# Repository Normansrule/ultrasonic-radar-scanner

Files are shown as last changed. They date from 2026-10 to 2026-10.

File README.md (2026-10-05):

# Ultrasonic Radar Scanner

**A tiny desk console that sweeps an ultrasonic "two-eye" head on a servo and draws what it hears as a green radar-style picture on a 2.8" touch screen.**
Three modules, seven wires, four printed parts, one USB cable.






<table>
<tr>
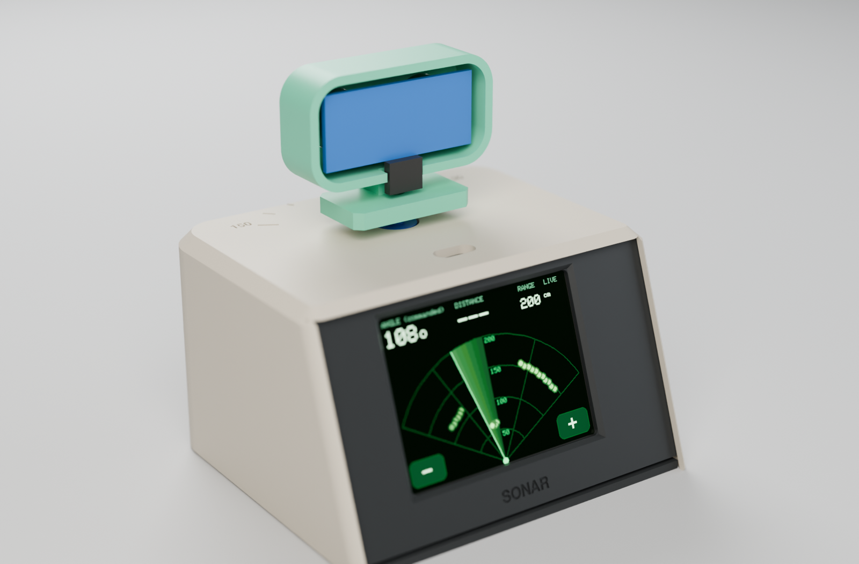
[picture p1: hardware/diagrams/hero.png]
Render: ivory console, screen tilted back, mint sensor head on a neck
<td width="62%"></td>
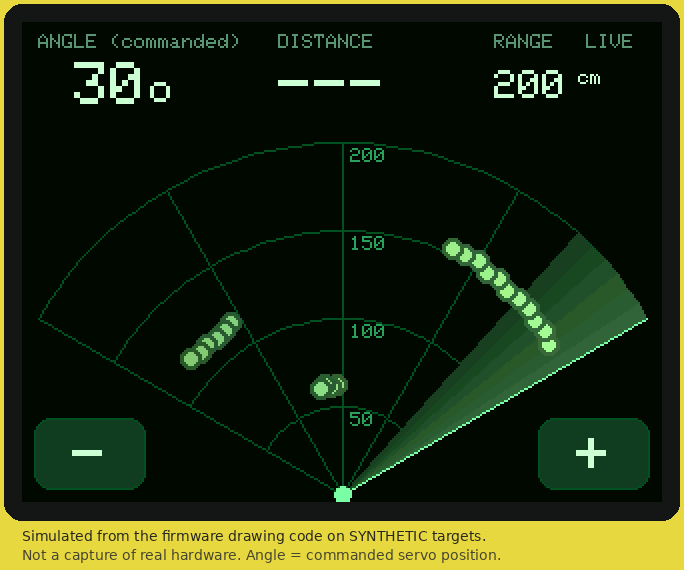
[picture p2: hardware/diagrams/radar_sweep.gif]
Simulated radar sweep
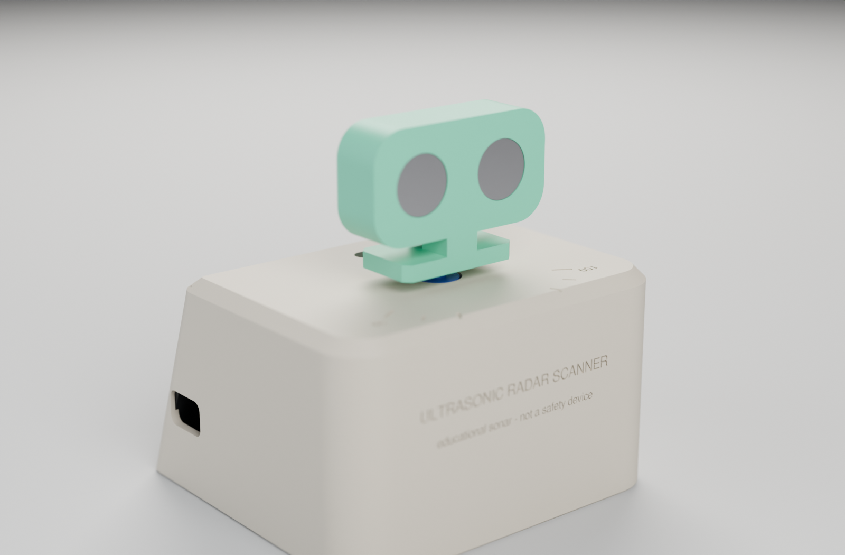
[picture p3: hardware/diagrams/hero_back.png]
Render from the scan side: the two ultrasonic eyes
<td width="38%"><br><br></td>
</tr>
<tr>
<td><sub>Render of the CadQuery model (Blender Cycles) — not a photo.</sub></td>
<td><sub>The firmware's drawing code on <b>synthetic</b> targets; the scan side.</sub></td>
</tr>
</table>

> [!IMPORTANT]
> **Educational sonar with a radar-*style* display. Not radio-frequency radar, and not a safety or obstacle-avoidance device.**
> It sweeps about 120°, and the angle shown is the *commanded* servo position. The CAD, firmware and apps pass automated checks,
> but **no V6 unit has been printed, wired or powered yet.** [`docs/VALIDATION.md`](docs/VALIDATION.md) tracks what is proven.

## The whole kit

Parts kit

| | Part | Est. US$ |
|---|---|---|
| 🖥️ | **ESP32-2432S028R "Cheap Yellow Display"** — ESP32, 2.8" 320 × 240 touch screen, RGB LED, USB | 12–20 |
| 🔊 | **RCWL-1601 or HC-SR04P** ultrasonic sensor (3.3 V version — no resistors needed) | 2–4 |
| ⚙️ | **SG90** micro servo, positional, with horn and its 2 screws | 2–3 |
| 🔌 | 3 × JST 1.25 mm 4-pin → Dupont cables, 3 male-male pins | 1–3 |
| 🖨️ | 4 printed parts, ≈ 120 g PLA, no supports | — |

Plus a USB cable and a ≥ 1 A charger or power bank. **About US$18–30 in total** — rough single-unit
estimates, not quotes. Details and what to check before buying: [`docs/BOM.md`](docs/BOM.md).

## Wire it — 7 wires

Seven wires

| Wire | From (CYD) | To |
|---|---|---|
| W1 | CN1 3.3V | sensor VCC |
| W2 | CN1 IO27 | sensor TRIG |
| W3 | P3 IO35 | sensor ECHO |
| W4 | CN1 GND | sensor GND |
| W5 | CN1 IO22 | servo signal (orange) |
| W6 | P1 VIN | servo + (red) — measure ≈ 5 V first |
| W7 | P1 GND | servo − (brown) |

Pin by pin, connector pinouts, power notes and the 5 V HC-SR04 fallback: [`docs/WIRING.md`](docs/WIRING.md).

## Build it

Build stages

1. **Print the fit coupon** — [`cad/3mf/plate_S1_fit_coupon.3mf`](cad/3mf/) — and pick peg, hole and screw sizes ([Printing](docs/PRINTING.md)).
2. **Bench test:** wire the 7 wires on the table and flash — [**Flash page**](https://normansrule.github.io/ultrasonic-radar-scanner/flash.html) in Chrome/Edge, or `arduino-cli compile --upload --profile esp32-core3 -p <port> firmware/Radar_V6`.
3. **Print** [`cad/3mf/radar_a1mini_multiplate.3mf`](cad/3mf/) — plate P1 (shell) and P2 (bezel, base, head).
4. **Assemble** in about 30 minutes ([Assembly](docs/ASSEMBLY.md)) — press fits and the servo's own two screws.
5. **Run and record** the tests in the [build packet](manufacturing/build_packet.pdf).

<table>
<tr>
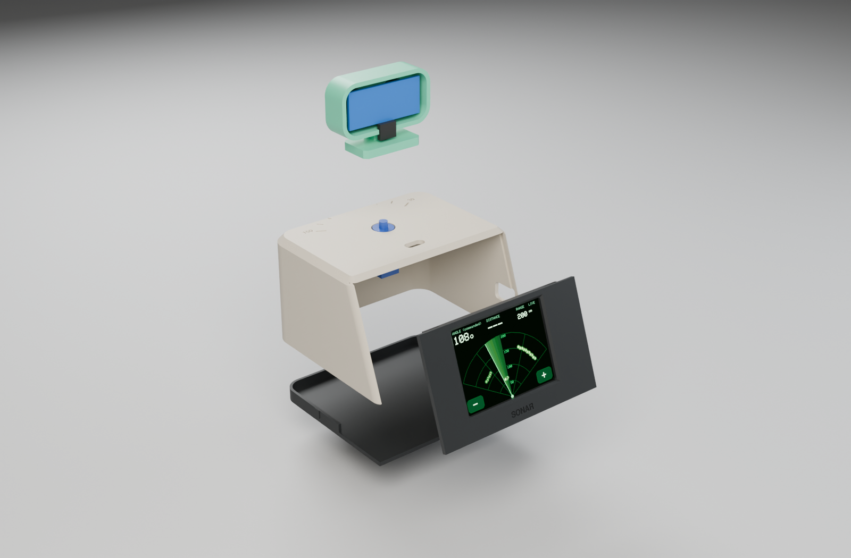
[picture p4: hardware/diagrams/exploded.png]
Exploded render
<td width="50%"></td>
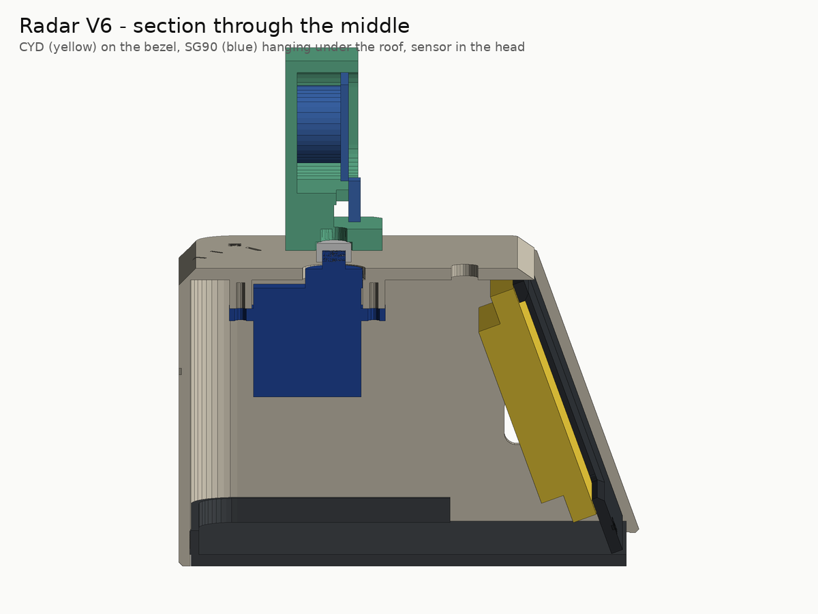
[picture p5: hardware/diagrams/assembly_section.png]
Section through the middle
<td width="50%"></td>
</tr>
<tr><td><sub>Shell · bezel (the CYD presses on) · base · head.</sub></td><td><sub>Section: CYD on the bezel, servo under the roof, sensor in the head.</sub></td></tr>
</table>

## Everything you need to make one

| | |
|---|---|
| 🧊 **3D files** | [`cad/3mf`](cad/3mf/) plates · [`cad/stl`](cad/stl/) · [`cad/step`](cad/step/) · source [`cad/build_radar.py`](cad/build_radar.py) (every dimension a named variable) |
| 🧾 **Parts list** | [`docs/BOM.md`](docs/BOM.md) · [`manufacturing/bom.csv`](manufacturing/bom.csv) |
| 🔌 **Circuit** | [`docs/WIRING.md`](docs/WIRING.md) · [`wiring_pins.csv`](manufacturing/wiring_pins.csv) · [`wire_list.csv`](manufacturing/wire_list.csv) |
| 📄 **Build packet** | [`manufacturing/build_packet.pdf`](manufacturing/build_packet.pdf) — print it, tick every step |
| ✅ **Requirements** | [`docs/REQUIREMENTS.md`](docs/REQUIREMENTS.md) — 33, each traced to a check or test |
| 💾 **Firmware** | [`firmware/Radar_V6`](firmware/Radar_V6/) — Arduino, pinned ESP32 core + libraries, compiles with 0 warnings |
| 🌐 **Apps** | [web app](https://normansrule.github.io/ultrasonic-radar-scanner/) (guide, simulator, live console, flasher) · desktop app on [Releases](https://github.com/Normansrule/ultrasonic-radar-scanner/releases/latest) |
| 📦 **Manufacturing kit** | one ZIP per [release](https://github.com/Normansrule/ultrasonic-radar-scanner/releases/latest): build packet, CSVs, 3MF/STL/STEP, diagrams, firmware |

## How it works

| | Equation | With the defaults |
|---|---|---|
| Distance | $d = v t / 2$, $v ≈ 331.3 + 0.606\,T$ | 5 823 µs at 20 °C → 100 cm |
| Servo | 50 Hz frame, 1.0–2.0 ms pulse, 16-bit duty | 90° → 1500 µs → 4915 |
| Sweep | $T = N_{moves}(t_{settle} + t_{overhead})$ | 40 × ~115 ms ≈ 4.6 s one way (estimate) |

Intuition, worked examples and plots: [`docs/EQUATIONS.md`](docs/EQUATIONS.md). Every number is re-checked by a test.

## Use it

* **On the device:** tap **−** / **+** to change the range (50–400 cm), tap the radar to pause. The LED turns red under 30 cm.
* **Live console:** plug the scanner into a computer — the same USB cable carries the readings — and open the
  [live console](https://normansrule.github.io/ultrasonic-radar-scanner/live.html) or the desktop app. Record and replay sessions ([`docs/LIVE_LINK.md`](docs/LIVE_LINK.md)).

## Publish, rebuild, contribute

* **Put it on GitHub from a fresh Ubuntu terminal:** one paste — [`docs/PUBLISH.md`](docs/PUBLISH.md).
* **Regenerate everything:** `python scripts/render_cad.py`, `render_previews.py`, `render_beauty.py` (Blender `bpy`), `sim_display.py`,
  `gen_diagrams.py`, `export_mfg.py`, `make_build_packet.py`, `gen_traceability.py`, `build_site.py`, then `python -m pytest tests`.
* **Built one?** Fill in the build packet's test sheet and send the results as a pull request to [`docs/VALIDATION.md`](docs/VALIDATION.md).

<details>
<summary><b>Repository layout</b></summary>

```
cad/build_radar.py           CadQuery source (model of record)
cad/3mf  cad/stl  cad/step    generated print files and editable CAD (never edit by hand)
firmware/Radar_V6/            Radar_V6.ino + sketch.yaml (pinned ESP32 core and libraries)
manufacturing/                bom.csv, printed_parts.csv, wiring_pins.csv, wire_list.csv, build_packet.pdf
docs/                         REQUIREMENTS, BOM, WIRING, PRINTING, ASSEMBLY, EQUATIONS, LIVE_LINK,
                              VALIDATION, SECURITY, PUBLISH, GLOSSARY
hardware/diagrams/            renders, wiring picture, parts kit, plates, GIF (all generated)
site/                         web app (GitHub Pages): landing, live console, flasher, guide
app/                          desktop app (Electron)
scripts/                      every generator, packager and exporter
tests/                        pytest, Node and browser checks
sbom/                         CycloneDX toolchain bill of materials
```
</details>

MIT licence · datasheets and credits in [`CREDITS.md`](CREDITS.md) · supply chain and electrical safety in [`docs/SECURITY.md`](docs/SECURITY.md) · terms in [`docs/GLOSSARY.md`](docs/GLOSSARY.md) · [`CHANGELOG.md`](CHANGELOG.md)

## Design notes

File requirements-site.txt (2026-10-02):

# Minimal set for building the GitHub Pages site and running the fast tests (no CAD kernel).
Markdown==3.10.2
pytest==9.1.1
# build packet PDF (scripts/make_build_packet.py)
reportlab==4.4.10
pillow==12.2.0

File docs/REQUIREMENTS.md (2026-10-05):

# Requirements and traceability

What the scanner must do, how each requirement is verified, and where the evidence lives.
Verification methods: **I**nspection, **A**nalysis, **D**emonstration, **T**est. Evidence IDs point to
[`VALIDATION.md`](VALIDATION.md): `R-…` are recorded checks a computer can run, `T-…` are physical tests.

**Status** is filled in by `python scripts/gen_traceability.py` from `VALIDATION.md`:
*Met (recorded)* = all evidence is a passing recorded check; *Open* = at least one physical test has not
been run yet. Values marked *target* are proposed goals for an educational instrument — confirm or
change them after the first bench runs.

<!-- REQS:BEGIN -->
| ID | Requirement | Method | Evidence | Status |
|---|---|---|---|---|
| RQ-F-01 | Sweep the sensor through a **commanded** 30°–150° in 3° steps and back, centring at boot. | D, A | R-EQ-1, T-FW-1, T-CAL-1 | Open |
| RQ-F-02 | Compute distance as d = v·t/2 and show 2 cm up to the selected range; show `---` for no echo or out of range. | A, T | R-EQ-1, T-FW-5 | Open |
| RQ-F-03 | Draw a radar-style display on the 320 × 240 screen: semicircular grid, sweep beam, fading detections, angle, distance and range readout. | D | R-FW-3, T-FW-1, T-FW-2 | Open |
| RQ-F-04 | Touch controls: − / + step the range through 50–400 cm; tapping the fan pauses and resumes. | D | R-FW-1, T-FW-6 | Open |
| RQ-F-05 | Provide `CENTER_ONLY` (head fitting), `REVERSE_SERVO` and `CALIBRATE_SERVO` modes. | D | R-FW-1, T-FW-3, T-CAL-1 | Open |
| RQ-F-06 | Print one `angle,distance` line per reading at 115 200 baud over the same USB cable for logging and the live console. | T | R-APP-1, T-LNK-1, T-LNK-2 | Open |
| RQ-F-07 | Run from one USB cable (charger or power bank ≥ 1 A); no battery inside. | T | R-BOM-1, T-PWR-1, T-PWR-2 | Open |
| RQ-F-08 | The on-board RGB LED turns red when something is closer than 30 cm. | D | R-FW-1, T-FW-7 | Open |
| RQ-P-01 | One-way sweep ≤ 5 s at default settings (estimate 4.6 s). | A, T | R-EQ-1, T-FW-4 | Open |
| RQ-P-02 | *Target:* distance within ±3 cm of a tape measure at 30, 100 and 150 cm on a flat target. | T | T-FW-5 | Open |
| RQ-P-03 | Servo travel calibrated without driving into its end stops. | T | T-CAL-1 | Open |
| RQ-P-04 | No resets or screen flicker over a one-hour run from a ≥ 1 A supply. | T | T-PWR-2, T-PWR-3, T-PWR-4 | Open |
| RQ-S-01 | The sensor runs from 3.3 V, so ECHO never exceeds the ESP32's 3.3 V logic; a 5 V-only sensor is used only with the documented divider. | A, I | R-EQ-1, R-SYNC-1 | Met (recorded) |
| RQ-S-02 | The servo is powered from VIN (USB 5 V), never from 3.3 V; VIN is measured before the servo is connected. | I, T | R-SYNC-1, T-PWR-1 | Open |
| RQ-S-03 | The USB serial (TX/RX) and backlight pins are never wired. | I | R-SYNC-1 | Met (recorded) |
| RQ-S-04 | The instrument is labelled "educational — not a safety device" on the case and the start-up screen. | I, D | R-CAD-1, R-FW-1, T-FW-1 | Open |
| RQ-S-05 | No part is uncomfortable to touch after 30 min running. | T | T-THM-1 | Open |
| RQ-I-01 | Every connection follows the `WIRING.md` net list, and firmware pin constants match it. | I | R-SYNC-1 | Met (recorded) |
| RQ-I-02 | ESP32-2432S028R (CYD) with ILI9341 or ST7789 panel; no flash pins used, no strapping pins on the external wires, no outputs on input-only pins. | I | R-SYNC-1, T-FW-2 | Open |
| RQ-I-03 | Seven wires, all through the CYD's JST connectors: no breadboard, no soldering to the board. | I | R-SYNC-1, R-MFG-1 | Met (recorded) |
| RQ-M-01 | Every printed part fits a Bambu Lab A1 mini (180 × 180 × 180 mm) and prints without supports. | A, T | R-CAD-3, T-PRN-2, T-PRN-3 | Open |
| RQ-M-02 | No loose fasteners: press fits plus the screws that come with the servo. | I, T | R-BOM-1, T-FIT-2, T-FIT-3 | Open |
| RQ-M-03 | The head and horn clear the shell and servo through the commanded travel plus 15° margin. | A, T | R-CAD-5, T-SWP-1 | Open |
| RQ-M-04 | Peg, sensor-hole and screw-pilot allowances are confirmed with the fit coupon before the full print. | T | T-PRN-1 | Open |
| RQ-M-05 | Modules (CYD, servo, sensor) fit without force; no model interference. | A, T | R-CAD-4, T-FIT-1, T-FIT-3, T-FIT-4 | Open |
| RQ-M-06 | All CAD outputs regenerate from one CadQuery source as valid, watertight single solids. | A | R-CAD-1, R-CAD-2 | Met (recorded) |
| RQ-M-07 | Minimum parts: 5 purchased items (+1 optional) and 4 printed parts. | I | R-BOM-1, R-MFG-1 | Met (recorded) |
| RQ-SW-01 | Firmware compiles with zero warnings on the pinned ESP32 cores 3.x and 2.x. | T | R-FW-1, R-FW-2 | Met (recorded) |
| RQ-SW-02 | No Wi-Fi or Bluetooth in the firmware; the consoles never write to the scanner. | I | R-SYNC-1, R-APP-5 | Met (recorded) |
| RQ-SW-03 | Build guide, simulator and live console work offline in the web app and the desktop app on Linux, Windows and macOS. | T | R-APP-2, R-APP-3, T-APP-1, T-APP-2 | Open |
| RQ-SW-04 | Firmware can be installed from a browser without installing a toolchain. | D | R-FLS-1, T-FLS-1 | Open |
| RQ-SW-05 | Every release carries checksums, a build-provenance attestation and a toolchain SBOM. | I | T-REL-1 | Open |
| RQ-O-01 | Everything needed to build it is in editable open formats (CadQuery, STEP, STL/3MF, Markdown, CSV) under the MIT licence. | I | R-CAD-1, R-BOM-1 | Met (recorded) |
<!-- REQS:END -->

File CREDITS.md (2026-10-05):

# Credits and sources

Every module datasheet the design relies on, and what was taken from it. "Checked" means the value
was read from the linked source while writing this repository (2026-09-30 to 2026-10-04); "unverified" means it
is a typical value that could not be confirmed from a primary source — treat it as a ## Module datasheets and product pages

| Module | Source | Used for | Status |
|---|---|---|---|
| ESP32-2432S028R "Cheap Yellow Display" | [witnessmenow/ESP32-Cheap-Yellow-Display](https://github.com/witnessmenow/ESP32-Cheap-Yellow-Display) (MIT) — `PINS.md`, schematics, community 3D model | display SPI (14/12/13/15/2, backlight 21), touch SPI (25/39/32/33/36), RGB LED (4/16/17, active low), connectors CN1 (GND/IO22/IO27/3.3V), P3 (GND/IO35/IO22/IO21), P1 (VIN/TX/RX/GND), board outline and holes | checked from the community documentation; **not** a manufacturer datasheet — clones vary, VERIFY |
| CYD pinout cross-checks | [Random Nerd Tutorials — CYD pinout](https://randomnerdtutorials.com/esp32-cheap-yellow-display-cyd-pinout-esp32-2432s028r/) · [Mischianti — ESP32-2432S028 pinout and schema](https://mischianti.org/esp32-2432s028-cheap-yellow-display-high-resolution-pinout-datasheet-schema-and-specs/) | same pins from independent write-ups; CYD2USB (ST7789) variant notes | cross-checked |
| ESP32 chip | [Espressif ESP32 series datasheet](https://www.espressif.com/sites/default/files/documentation/esp32_datasheet_en.pdf) | input-high threshold 0.75·VDD, absolute maximum VDD + 0.3 V, strapping pins (0, 2, 5, 12, 15), flash pins (6–11), input-only pins (34–39) | values as commonly quoted — confirm in the DC-characteristics table |
| RCWL-1601 ultrasonic sensor | [Adafruit 4007 — Ultrasonic Distance Sensor, 3 V or 5 V](https://www.adafruit.com/product/4007) | runs from 3–5 V, so at 3.3 V its ECHO is 3.3 V logic; HC-SR04 footprint | checked (product page) |
| HC-SR04 (footprint and fallback) | [ElecFreaks HC-SR04 datasheet (SparkFun mirror)](https://cdn.sparkfun.com/datasheets/Sensors/Proximity/HCSR04.pdf) | 10 µs trigger, ECHO pulse width ∝ distance, ≥ 60 ms cycle, 45 × 20 mm board, 5 V ECHO on the classic part | datasheet located; can diameter and pitch **unverified** across clones |
| ILI9341 controller | [Adafruit ILI9341 library](https://github.com/adafruit/Adafruit_ILI9341) | panel ID read (0xD3 → 0x93 0x41) for auto-detection | used as implemented in the library |
| XPT2046 touch controller | [PaulStoffregen/XPT2046_Touchscreen](https://github.com/PaulStoffregen/XPT2046_Touchscreen) | touch on its own SPI bus | used as implemented |
| SG90 servo | [TowerPro SG90 datasheet (DatasheetCafe copy)](https://www.datasheetcafe.com/sg90-datasheet-pdf-9-g-micro-servo/) | 22.2 × 11.8 × 31 mm, 4.8–5 V, 0.1 s/60°, 10 µs dead band | overall size checked; flange, hole pitch, shaft offset and horn dimensions **unverified** |

verified** |

## Software and references

| Item | Source |
|---|---|
| ESP Web Tools 10.4.0 (browser flasher) | [github.com/esphome/esp-web-tools](https://github.com/esphome/esp-web-tools) (Apache-2.0), loaded from unpkg.com on the Flash page |
| ReportLab 4.4 (build packet PDF) | [reportlab.com/opensource](https://www.reportlab.com/opensource/) (BSD) |
| DejaVu Sans fonts (in `manufacturing/fonts/`) | [dejavu-fonts.github.io](https://dejavu-fonts.github.io/) — Bitstream Vera licence, copy in `manufacturing/fonts/LICENSE-DejaVu.txt` |
| Arduino-ESP32 core, LEDC API | [Espressif — LEDC API](https://docs.espressif.com/projects/arduino-esp32/en/latest/api/ledc.html) and the [2.x → 3.0 migration guide](https://docs.espressif.com/projects/arduino-esp32/en/latest/migration_guides/2.x_to_3.0.html) (ledcSetup/ledcAttachPin → ledcAttach) |
| Adafruit GFX Library 1.12.6 | [github.com/adafruit/Adafruit-GFX-Library](https://github.com/adafruit/Adafruit-GFX-Library) (BSD licence) |
| Adafruit ILI9341 1.6.4 | [github.com/adafruit/Adafruit_ILI9341](https://github.com/adafruit/Adafruit_ILI9341) (MIT licence) |
| XPT2046_Touchscreen 1.4 | [github.com/PaulStoffregen/XPT2046_Touchscreen](https://github.com/PaulStoffregen/XPT2046_Touchscreen) |
| Blender 4.2 (`bpy`, renders) | [blender.org](https://www.blender.org/) (GPL; used as a tool, nothing redistributed) |
| Adafruit ST7735 and ST7789 Library 1.11.0 | [github.com/adafruit/Adafruit-ST7735-Library](https://github.com/adafruit/Adafruit-ST7735-Library) (MIT licence) |
| Adafruit BusIO 1.17.4 | [github.com/adafruit/Adafruit_BusIO](https://github.com/adafruit/Adafruit_BusIO) (MIT licence) |
| CadQuery 2.8 | [github.com/CadQuery/cadquery](https://github.com/CadQuery/cadquery) (Apache 2.0) |
| arduino-cli sketch profiles | [Arduino CLI — sketch project file](https://arduino.github.io/arduino-cli/latest/sketch-project-file/) |
| OWASP Top 10:2025 — A03 Software Supply Chain Failures | [owasp.org/Top10/2025/A03_2025-Software_Supply_Chain_Failures](https://owasp.org/Top10/2025/A03_2025-Software_Supply_Chain_Failures/) |
| Speed of sound in air, $v ≈ 331.3 + 0.606\,T$ | standard linear approximation for dry air near room temperature; e.g. [Wikipedia — Speed of sound](https://en.wikipedia.org/wiki/Speed_of_sound) |

The display simulator (`scripts/sim_display.py`) reads the 5×7 font from your locally installed
Adafruit GFX library at run time; the font is not redistributed here.

## People

Design, brief and project ownership: Aleksander Norman. Repository structure, CadQuery model,
firmware, generators and documentation drafted with AI assistance (Claude, Anthropic) and to be
reviewed and physically validated by the maintainer.

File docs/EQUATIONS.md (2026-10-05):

# Equations — how the numbers work

Every equation below follows the same pattern: **plain intuition → equation → symbols and units
→ worked example → picture.** Every number on this page is re-computed by
[`tests/test_equations.py`](../tests/test_equations.py) from one reference implementation,
[`tests/radar_math.py`](../tests/radar_math.py), whose integer maths mirrors the firmware. If a
number here and the test disagree, the test wins.

Run the checks: `python -m pytest tests/test_equations.py -v`

---

## 1. Ultrasonic distance

**Intuition.** The sensor (RCWL-1601 / HC-SR04P) clicks out a short burst of 40 kHz sound and holds its ECHO pin HIGH
until the echo comes back. Sound travels to the object *and back*, so the object is half as far
away as the total path the sound covered.

**Equation.**

$$d = \frac{v \cdot t}{2}, \qquad v \approx 331.3 + 0.606\,T$$

| Symbol | Meaning | Unit |
|---|---|---|
| $d$ | distance from the sensor face to the object | cm (firmware) |
| $v$ | speed of sound in air | m/s (÷10 000 → cm/µs) |
| $t$ | time the ECHO pin stays HIGH | µs |
| $T$ | air temperature | °C |

**Worked example.** At 20 °C, $v = 331.3 + 0.606 \times 20 = 343.42$ m/s $= 0.034342$ cm/µs.
An ECHO pulse of 5 823 µs gives $d = 5823 \times 0.034342 / 2 = 99.99 \approx 100.0$ cm.
Going the other way, 100 cm needs $t = 2 \times 100 / 0.034342 \approx 5 824$ µs.

**Temperature matters.** The same echo converted with the 20 °C constant on a 35 °C day reads
about **2.6 % short** (97.4 cm instead of 100 cm). The firmware has an `AIR_TEMP_C` setting
because there is no temperature sensor in this build.

**Timeout.** The firmware stops waiting after the round trip for 110 % of the display range, plus
1 ms for the burst to start: $2 \times 220 / 0.034342 + 1000 = 13 812$ µs. A timeout shows `---`.

Distance versus echo time at three temperatures

---

## 2. ECHO level — why V6 needs no divider

**Intuition.** The ESP32's pins are 3.3 V parts. The 3.3 V-capable sensor (RCWL-1601 / HC-SR04P) is
powered from the board's 3.3 V, so its ECHO pin can never go above 3.3 V: it connects straight to
IO35. Above the logic-HIGH threshold $0.75\,V_{DD} \approx 2.48$ V, below the absolute maximum
$V_{DD} + 0.3 \approx 3.6$ V.

**Fallback (only with a 5 V-only HC-SR04).** Its ECHO swings to 5 V. Two resistors share that in
proportion to their values:

$$V_{out} = V_{in} \cdot \frac{R_2}{R_1 + R_2}$$

| Symbol | Meaning | Value |
|---|---|---|
| $V_{in}$ | ECHO high level | 5.0 V nominal |
| $R_1$ | top resistor (ECHO → junction) | 2.2 kΩ |
| $R_2$ | bottom resistor (junction → GND) | 3.3 kΩ |
| $V_{out}$ | voltage at IO35 | V |

**Worked example.** $V_{out} = 5.0 \times 3.3 / (2.2 + 3.3) = 3.00$ V, about 0.91 mA through the pair.
With 5.25 V and 1 % resistors it stays between 3.12 V and 3.18 V; at 4.75 V it is still ≥ 2.82 V.

Divider transfer line with the ESP32 limits

---

## 3. Servo timing and the LEDC duty

**Intuition.** A hobby servo expects one pulse every 20 ms. The *width* of the pulse is the
command: about 1.0 ms means one end, 1.5 ms the middle, 2.0 ms the other end. The ESP32's LED
Control (LEDC) peripheral makes this pulse in hardware by counting up to a "duty" value inside
each 20 ms frame.

**Equations.**

$$T_{frame} = \frac{1}{f} = \frac{1}{50\,\text{Hz}} = 20\,000\ \mu s$$

$$\text{pulse}(\theta) = P_0 + (P_{180} - P_0)\cdot\frac{\theta}{180}$$

$$\text{duty} = \left\lfloor \frac{\text{pulse} \cdot (2^{16} - 1)}{T_{frame}} \right\rfloor$$

| Symbol | Meaning | Default |
|---|---|---|
| $f$ | PWM frequency | 50 Hz |
| $\theta$ | **commanded** angle (not measured) | 30–150° |
| $P_0$, $P_{180}$ | pulse widths mapped to 0° and 180° | 1000 µs, 2000 µs |
| duty | LEDC compare value, 16-bit resolution | counts out of 65 535 |

**Worked example.** 90° → $1000 + 1000 \times 90/180 = 1500$ µs → duty
$\lfloor 1500 \times 65535 / 20000 \rfloor = 4915$ (7.5 % of the frame). 30° → 1166 µs → 3820;
150° → 1833 µs → 6006. One LEDC count is about 0.31 µs, far finer than the servo's ≈10 µs dead band.

**Why 1000–2000 µs is only a starting point.** Many SG90s travel further than 90° for 1.0–2.0 ms,
so the *real* head angle may not equal the *commanded* angle on screen. Use `CALIBRATE_SERVO` and the
tick marks engraved on the roof to adjust `SERVO_US_AT_0` / `SERVO_US_AT_180`, and **never widen the
map so far that the servo buzzes against its internal stops**. A hard clamp (`SERVO_US_GUARD_MIN/MAX`,
900–2100 µs) protects against a bad edit.

Pulse widths for 30, 90 and 150 degrees

---

## 4. Sweep cadence

**Intuition.** Each reading costs a fixed wait for the servo to settle, plus the time to ping and
redraw the screen. The number of readings per pass is fixed by the step size. Multiply.

**Equations.**

$$N_{moves} = \frac{\theta_{max} - \theta_{min}}{\Delta\theta}, \qquad
T_{step} = t_{settle} + t_{overhead}, \qquad
T_{one\,way} = N_{moves} \cdot T_{step}$$

$$f_{refresh} = \frac{1}{T_{step}} \quad\text{(one full frame is drawn per reading)}$$

| Symbol | Meaning | Default |
|---|---|---|
| $\Delta\theta$ | step | 3° |
| $\theta_{min}, \theta_{max}$ | sweep limits (commanded) | 30°, 150° |
| $t_{settle}$ | wait after each move | 70 ms |
| $t_{overhead}$ | ping + draw + SPI frame push | **≈45 ms — ESTIMATE** |

**Worked example.** $N = 120/3 = 40$ moves (41 readings per pass). The screen push alone is
$320 \times 240 \times 16\ \text{bit} / 40\ \text{MHz} \approx 30.7$ ms; add ≈8 ms drawing and ≈6 ms
for a ~1 m echo → $t_{overhead} \approx 45$ ms, $T_{step} \approx 115$ ms, one way ≈ **4.6 s**, a full
round trip ≈ 9.2 s, screen refresh ≈ 8.7 frames/s. Detections live for 10 s, longer than one round
trip, so each dot stays until its angle is revisited.

**This is an estimate, not a measurement.** The firmware prints the measured mean step time and
one-way sweep time over serial after every pass — record the real numbers in
[`VALIDATION.md`](VALIDATION.md) (test T-FW-4). Two sanity checks that *are* derived: a 3° move at
the SG90's ~0.1 s/60° takes ~5 ms (well inside the 70 ms settle), and the ≥70 ms cycle respects the
common HC-SR04-family guidance of ≥60 ms between pings so old echoes die away.

Sweep period against settle time for three step sizes

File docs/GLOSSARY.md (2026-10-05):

# Glossary

Every abbreviation is written out once with its short form in brackets, as used in the rest of the
documentation.

| Term | Meaning |
|---|---|
| 3D Manufacturing Format (3MF) | A print-file format that can hold several objects, their placement and slicer settings in one file. |
| Bill of Materials (BOM) | The shopping list: every part, how many, and what to check. |
| Build packet | The printable PDF traveller in `manufacturing/` with tick boxes for every part, wire, gate and test. |
| CadQuery | A Python library for writing 3D models as code. `cad/build_radar.py` is the model of record. |
| Cheap Yellow Display (CYD) | Community name for the ESP32-2432S028R: an ESP32, a 2.8" 320 × 240 touch screen, an RGB LED and USB on one yellow board. |
| JST 1.25 mm connector | The small 4-pin sockets on the back of the CYD (CN1, P3, P1); cables with a JST plug on one end and Dupont sockets on the other plug into them. |
| Dupont connector | The 2.54 mm push-on jumper connector used on hobby modules and servo plugs. |
| ILI9341 / ST7789 | The two display controller chips found on CYD boards; the firmware detects which one you have. |
| XPT2046 | The CYD's resistive touch controller. |
| Press fit | A joint held by friction because the hole is very slightly smaller than the part pushed into it. |
| Crush rib | A thin printed ridge that deforms slightly to make a firm press fit. |
| VIN | The CYD's P1 pin that carries the USB 5 V; it powers the servo. |
| Liquid-Crystal Display (LCD) / Thin-Film Transistor (TFT) | The colour screen technology on the CYD. |
| Commanded angle | The angle the firmware *asks* the servo for. Nothing measures the real angle. |
| CycloneDX | A standard file format for a software bill of materials. |
| Duty (cycle) | The fraction of each PWM period that the signal is high. |
| ECHO / TRIG | Ultrasonic sensor pins: a 10 µs pulse on TRIG starts a ping; ECHO stays high for as long as the sound took to return. |
| Electrostatic discharge (ESD) | Static shocks that can damage modules — touch something grounded before handling boards. |
| AppImage | A single-file Linux application format; make it executable and run it. |
| Content Security Policy (CSP) | Browser rules that limit what a page may load or run; the desktop app's pages carry a strict one. |
| Electron | A framework that wraps web pages in a desktop window; used for the desktop app. |
| ESP Web Tools | An open-source web page component that flashes ESP32 boards from Chrome or Edge; used on the Flash page. |
| Fit coupon | A small printed test piece that checks hole and slot sizes before the long prints. |
| General-Purpose Input/Output (GPIO) | A numbered microcontroller pin that firmware can read or drive. |
| Ground (GND) | The shared 0 V reference all voltages are measured from. |
| Horn | The plastic arm supplied with a servo that grips its splined output shaft. |
| LED Control (LEDC) | The ESP32 peripheral that generates PWM in hardware; used here for the servo. |
| Net | Every pin that is electrically connected together. |
| Merged image | One firmware file containing bootloader, partition table and app, flashed at address 0x0. |
| Progressive Web App (PWA) | A website that can be installed and used offline like an app. |
| Polylactic acid (PLA) | The plastic used for printing. |
| Printed Circuit Board (PCB) | A board with copper tracks. This project uses ready-made module boards and no custom PCB. |
| Pulse-Width Modulation (PWM) | A repeating square wave whose high time carries a value. |
| Radar-style display | A fan-shaped picture like a radar screen. The sensing here is ultrasonic, not radio. |
| Serial Peripheral Interface (SPI) | A fast clocked bus; the CYD's screen and touch controller each use one. |
| Software Bill of Materials (SBOM) | A list of the software components and exact versions used to build the project. |
| Traceability | Linking every requirement to the check or test that proves it (`docs/REQUIREMENTS.md`). |
| Spline | The toothed servo output shaft. |
| Standard for the Exchange of Product model data (STEP) | A precise CAD exchange format for editing the parts in other CAD tools. |
| Stereolithography file (STL) | A triangle-mesh file that slicers read. |
| Strapping pin | An ESP32 pin whose level at power-up selects a boot mode (GPIO 0, 2, 5, 12, 15) — avoided here. |
| Universal Asynchronous Receiver-Transmitter (UART) | The serial port the firmware prints on (115 200 baud); it reaches the computer through the CYD's USB chip. |
| VERIFY | A CAD dimension that depends on your purchased module and must be measured before printing the full set. |
| Voltage divider | Two resistors in series that output a fixed fraction of their input voltage. |
| Web Serial | The browser interface (Chrome/Edge, and the desktop app) that lets a page read a serial port after you pick it. |
| Windows Subsystem for Linux (WSL) | Runs Ubuntu inside Windows; the publish script supports it. |

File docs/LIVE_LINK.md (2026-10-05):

# Live link and apps

The project ships in two forms built from the same files:

| Form | Where | Works offline | Live link to the scanner |
|---|---|---|---|
| **Web app** | the GitHub Pages site — open it in any browser; "Install web app" adds it to your desktop or phone home screen (a Progressive Web App (PWA)) | yes, after the first visit | Chrome or Edge on a desktop (Web Serial API) |
| **Desktop app** | Releases page: Windows installer or portable `.exe`, macOS `.dmg`, Linux `.AppImage` / `.tar.gz` | always (guide, simulator, console are bundled) | yes, on Windows, macOS and Linux |

Both contain the build guide, the sweep simulator, the wiring explorer and the **live console**.
The console has three sources, all decoded by the same parser
([`site/assets/radar-core.js`](../site/assets/radar-core.js)):

* **Connect scanner** — reads the firmware's serial output (115 200 baud, `angle_deg,distance_cm` lines).
* **Replay a log** — plays back a saved session, or any serial log, in any browser.
* **Demo** — synthetic targets, clearly labelled, for trying the console without hardware.

It can **record** a session and save it as CSV (`host_ms,angle_deg,distance_cm`) — use this for the
validation tests T-FW-4, T-FW-5 and T-LNK-1. The console **only listens**: it never sends a byte to the scanner.

Status: the parser, renderer, replay and demo are tested automatically (see
[`VALIDATION.md`](VALIDATION.md)); **the live serial link has never been connected to a real
scanner.** The desktop app has been built and smoke-tested on Linux only; the Windows and macOS
builds are produced by GitHub Actions on each release and are unsigned.

## Connecting the scanner

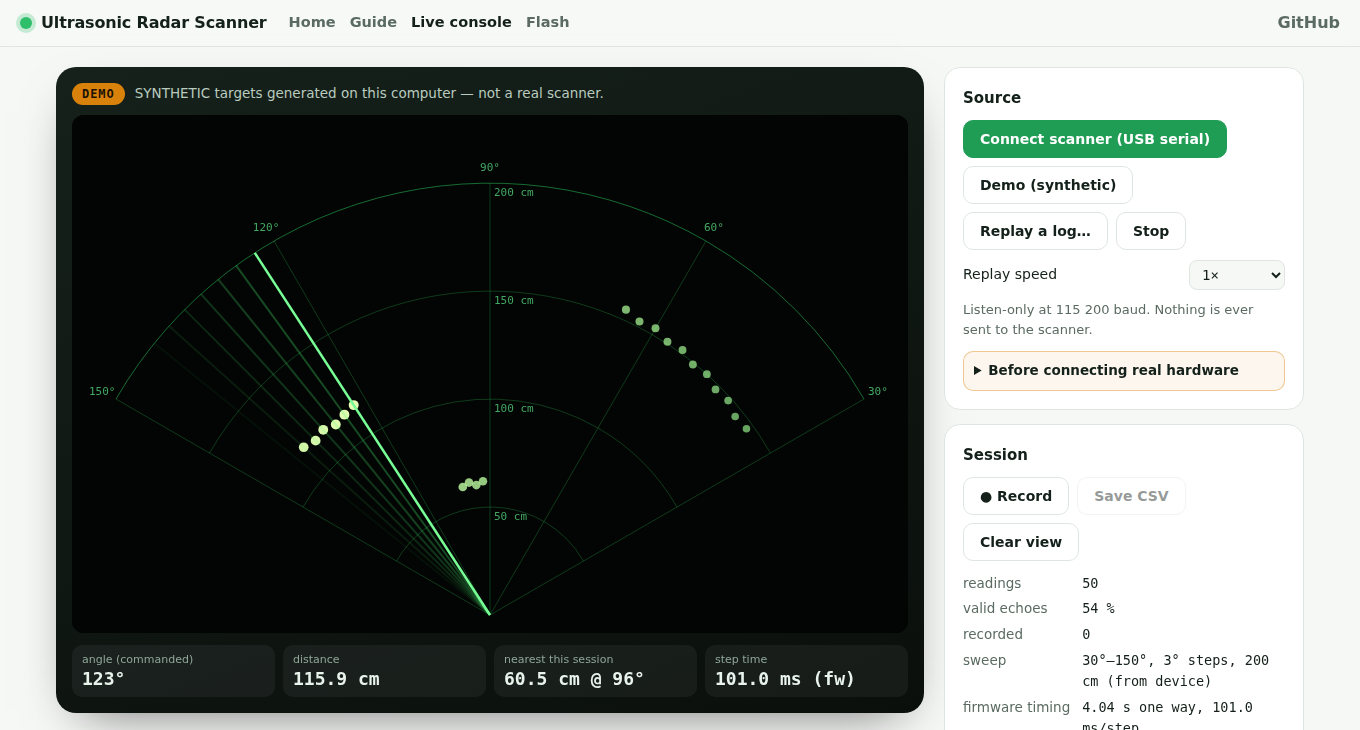
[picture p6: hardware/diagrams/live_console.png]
Live console


The Cheap Yellow Display has a USB-to-serial chip on board, so the **same USB cable that powers the
scanner** carries its readings. No extra wires or adapters.

1. Plug the scanner into the computer. Use a port or powered hub that can supply about 1 A; a weak
   port may make the board reset when the servo starts (see [Wiring → Power](WIRING.md#power--read-this)).
2. Open the **Live console** (web app in Chrome/Edge, or the desktop app) → **Connect scanner** →
   pick the port (CH340 or CP210x, depending on your board). Linux: if the port is refused, add yourself
   to the `dialout` group (`sudo usermod -aG dialout $USER`, then log out and in).
3. Opening the port may **restart** the board (the USB chip's reset lines). The sweep just starts again.
4. Nothing appears? Check the baud rate is 115 200 and that no other program (Arduino serial monitor)
   has the port open.

## Installing the desktop app

Download from the repository's **Releases** page (the latest release is linked from the web app).

| System | File | Notes |
|---|---|---|
| Windows 10/11 | `…-win-x64.exe` (installer) or `…-portable-x64.exe` | Unsigned: SmartScreen shows "unknown publisher" → *More info* → *Run anyway*. |
| macOS 12+ | `…-mac-arm64.dmg` (Apple silicon) or `…-mac-x64.dmg` (Intel) | Unsigned: first launch is blocked → System Settings → Privacy & Security → *Open Anyway*. |
| Linux x64 | `…-linux-x86_64.AppImage` or `…-linux-x64.tar.gz` | AppImage needs FUSE 2 (`sudo apt install libfuse2t64` on Ubuntu 24.04+); the `.tar.gz` needs nothing — unpack and run `ultrasonic-radar-scanner`. If it exits with a sandbox error (Ubuntu 24.04+ AppArmor), start it with `--no-sandbox`. |

Every release carries `SHA256SUMS` and a signed build-provenance attestation — see
[`SECURITY.md`](SECURITY.md#verifying-a-release-yourself).

## Building the apps yourself

```bash
# web app (GitHub Pages output in site/)
python -m pip install -r requirements-site.txt
python scripts/build_site.py

# desktop app
cd app
npm ci                                         # Electron, electron-builder, KaTeX (versions pinned in package-lock.json)
python ../scripts/build_site.py --app --out web
npm start                                      # run it
npm run dist                                   # build installers for this OS into app/dist/
```

The desktop app is a locked-down Electron window around the same pages: no Node.js access in the
page, sandboxed renderer, context isolation, a strict Content Security Policy (CSP), external links
open in your normal browser, and every browser permission except serial-port access is refused.

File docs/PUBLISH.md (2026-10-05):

# Publishing: repository, web app and desktop app (Ubuntu)

Two copy-and-paste blocks for an Ubuntu terminal (native or Windows Subsystem for Linux (WSL)).

1. **Publish** — pushes the repository, turns on the **web app** (GitHub Pages) and tags release
   `v6.0.0`; GitHub Actions then builds the **desktop app** (Windows, macOS, Linux), the **firmware
   images** and the **manufacturing kit** and attaches them to the release.
2. **Keep building** — sets up a local workspace: tests, the web app, the desktop app from source and
   (optionally) the firmware compile.

Both run inside `( … )`, so an error stops the block without closing your terminal, and both are safe
to paste again.

## 1 — Publish (repository, web app, desktop app, manufacturing kit)

What it does, in order: installs `git` + GitHub CLI (`gh`), signs you in, unpacks the newest ZIP from
Downloads, commits, creates the public repository, pushes, turns on the **web app** (GitHub Pages,
including the firmware flasher), and tags release **v6.0.0**. The release workflow then builds and
attaches the **desktop apps**, **firmware images** and the **manufacturing kit**.

* Edit `OWNER` on the first line if the repository should belong to another GitHub account.
* The only interactive step is a GitHub browser sign-in (skipped if `gh` is already signed in as `OWNER`).
* On a fresh Ubuntu it installs `gh` from Ubuntu, or from GitHub's own apt repository if Ubuntu's copy is
  missing or older than 2.40.
* If `~/.ssh/config` has `Host github-normansrule`, it pushes over that SSH alias; otherwise over HTTPS
  through `gh` (with the `workflow` scope GitHub requires for `.github/workflows/`).
* ZIP: newest `ultrasonic-radar-scanner*.zip` in `~/Downloads` or the Windows Downloads folders (WSL);
  mirrored into `~/projects/ultrasonic-radar-scanner` (files an older version left behind are removed; `.git`, `.venv` and `node_modules` are kept). It never runs Git in your home folder.
* `sudo` is used only for package installation. Safe to paste again.
* Web app: about 5 minutes. Release builds: roughly 15–25 minutes; the block waits up to 40 minutes
  and lists the files — **Ctrl+C is safe** by then, everything is already pushed.

```bash
(
set -euo pipefail
OWNER="Normansrule"; REPO="ultrasonic-radar-scanner"; TAG="v6.0.0"; SSH_ALIAS="github-normansrule"
# 1. Install git, unzip, rsync, curl and the GitHub CLI (Ubuntu's gh if >= 2.40, else GitHub's official apt repo)
sudo apt-get update -y; sudo apt-get install -y git unzip rsync curl ca-certificates; sudo apt-get install -y gh || true
if ! command -v gh >/dev/null || [ "$(printf '%s\n' 2.40.0 "$(gh --version | awk 'NR==1{print $3}')" | sort -V | head -n1)" != "2.40.0" ]; then sudo install -d -m 755 /etc/apt/keyrings; curl -fsSL https://cli.github.com/packages/githubcli-archive-keyring.gpg | sudo tee /etc/apt/keyrings/githubcli-archive-keyring.gpg >/dev/null; sudo chmod go+r /etc/apt/keyrings/githubcli-archive-keyring.gpg; echo "deb [arch=$(dpkg --print-architecture) signed-by=/etc/apt/keyrings/githubcli-archive-keyring.gpg] https://cli.github.com/packages stable main" | sudo tee /etc/apt/sources.list.d/github-cli.list >/dev/null; sudo apt-get update -y; sudo apt-get install -y gh; fi; gh --version | head -n1
# 2. Make sure gh is signed in as $OWNER (switches account if already added; browser sign-in otherwise)
gh auth switch -h github.com -u "$OWNER" >/dev/null 2>&1 || true
[ "$(gh api user -q .login 2>/dev/null || true)" = "$OWNER" ] || gh auth login -h github.com -p https -w -s workflow
[ "$(gh api user -q .login)" = "$OWNER" ] || { echo "gh is signed in as $(gh api user -q .login), not $OWNER - edit OWNER or sign in again"; exit 1; }
# 3. Choose the push route: your SSH alias for this account if it exists, otherwise HTTPS via gh (needs 'workflow' scope)
if grep -qsiE "^[[:space:]]*Host[[:space:]]+$SSH_ALIAS([[:space:]]|$)" ~/.ssh/config; then REMOTE="git@$SSH_ALIAS:$OWNER/$REPO.git"; export GIT_SSH_COMMAND="ssh -o StrictHostKeyChecking=accept-new"; else REMOTE="https://github.com/$OWNER/$REPO.git"; gh api -i user 2>/dev/null | grep -i '^x-oauth-scopes:' | grep workflow >/dev/null || gh auth refresh -h github.com -s workflow; gh auth setup-git -h github.com; fi; echo "Push route: $REMOTE"
# 4. Find the newest ZIP (Linux ~/Downloads, then Windows Downloads under WSL) and check it is this version
ZIP="$(ls -t ~/Downloads/$REPO*.zip /mnt/c/Users/*/Downloads/$REPO*.zip 2>/dev/null | head -n1 || true)"; [ -n "$ZIP" ] || { echo "No $REPO*.zip in ~/Downloads"; exit 1; }
unzip -Z1 "$ZIP" | grep -x "$REPO/firmware/Radar_V6/Radar_V6.ino" >/dev/null || { echo "$ZIP is an older ZIP - download the new one"; exit 1; }; echo "Using $ZIP"
# 5. Unpack into ~/projects/$REPO: mirror the ZIP exactly (removes files an older version left behind; keeps .git, .venv, node_modules)
mkdir -p ~/projects/"$REPO"; TMP="$(mktemp -d)"; unzip -q "$ZIP" -d "$TMP"; [ -f "$TMP/$REPO/README.md" ] || { echo "Unexpected ZIP layout"; exit 1; }
rsync -a --delete --exclude /.git --exclude /.venv --exclude /app/node_modules --exclude /app/dist "$TMP/$REPO/" ~/projects/"$REPO"/; rm -rf "$TMP"; cd ~/projects/"$REPO"
# 6. Initialise Git on main (guard: never in your home folder); set a commit identity for this repo only if none is configured
[ "$PWD" = "$HOME/projects/$REPO" ] || { echo "Not in ~/projects/$REPO - stopping"; exit 1; }
[ -d .git ] || git init -q -b main
git config user.name >/dev/null || git config user.name "$(gh api user -q '.name // .login')"; git config user.email >/dev/null || git config user.email "$(gh api user -q .id)+$OWNER@users.noreply.github.com"
# 7. Commit everything (only when something changed)
git add -A; git diff --cached --quiet || git commit -q -m "Ultrasonic Radar Scanner $TAG: Radar V6 Mini - 3 modules, 7 wires, 4 printed parts (CAD, BOM, wiring, build packet, firmware, web + desktop apps)"
# 8. Create the public repository if missing; set description, homepage and topics
gh repo view "$OWNER/$REPO" >/dev/null 2>&1 || gh repo create "$OWNER/$REPO" --public --description "Open-hardware educational ultrasonic (sonar) scanner with a radar-style display - Cheap Yellow Display, 3.3 V ultrasonic sensor, SG90, 4 printed parts, 7 wires"
gh repo edit "$OWNER/$REPO" --homepage "https://${OWNER,,}.github.io/$REPO/" --add-topic open-hardware,esp32,cheap-yellow-display,ultrasonic,sonar,cadquery,3d-printing,electron,education >/dev/null
# 9. Point 'origin' at the repository and push main
git remote get-url origin >/dev/null 2>&1 && git remote set-url origin "$REMOTE" || git remote add origin "$REMOTE"
git branch -M main; git push -u origin main
# 10. WEB APP: enable GitHub Pages (built by the Pages workflow, which also compiles the firmware for the flasher)
gh api -X POST "repos/$OWNER/$REPO/pages" -f build_type=workflow >/dev/null 2>&1 || gh api -X PUT "repos/$OWNER/$REPO/pages" -f build_type=workflow >/dev/null
for i in 1 2 3 4 5 6; do gh workflow run pages.yml -R "$OWNER/$REPO" --ref main >/dev/null 2>&1 && break; sleep 10; done
# 11. RELEASE: tag it; Actions builds desktop apps, firmware images and the manufacturing kit and attaches them
git rev-parse -q --verify "refs/tags/$TAG" >/dev/null || git tag -a "$TAG" -m "Ultrasonic Radar Scanner $TAG"
git push origin "refs/tags/$TAG" || echo "Tag $TAG already exists on GitHub with different contents - bump the version for a new release"
# 12. Wait for the web app (up to 5 min) and print its addresses
URL="$(gh api "repos/$OWNER/$REPO/pages" -q .html_url)"; for i in $(seq 1 30); do [ "$(curl -s -o /dev/null -w '%{http_code}' "$URL")" = "200" ] && break; sleep 10; done; echo; echo "Repository: https://github.com/$OWNER/$REPO"; echo "Web app:    $URL"; echo "Flasher:    ${URL}flash.html"; echo "Console:    ${URL}live.html"
# 13. Wait for the release (up to 40 min; Ctrl+C is safe - everything is pushed) and list the downloads
echo "Release building: https://github.com/$OWNER/$REPO/actions/workflows/release.yml"; for i in $(seq 1 80); do n="$(gh release view "$TAG" -R "$OWNER/$REPO" --json assets -q '.assets|length' 2>/dev/null || echo 0)"; [ "$n" -ge 10 ] && break; printf '.'; sleep 30; done; echo
gh release view "$TAG" -R "$OWNER/$REPO" --json assets -q '.assets[].name' 2>/dev/null | sed 's/^/  /' || echo "Release not ready yet - check the Actions link above"; echo "Release:    https://github.com/$OWNER/$REPO/releases/tag/$TAG"
)
```

If the web app is not live, open the repository's **Actions** tab, read the "Pages" run, fix and paste
again. If a release build failed, re-run it from its run page or with
`gh workflow run release.yml -R Normansrule/ultrasonic-radar-scanner -f tag=v6.0.0`.

## 2 — Keep building locally

Run this after block 1, in the same terminal or a new one. It:

* creates a Python virtual environment for the site and tests;
* runs every fast test;
* builds the web app and serves it at `http://localhost:8000`;
* installs Node.js 22 through nvm if your system Node is older (Electron 44 needs 22.12+), then the desktop app's pinned toolchain, and launches the desktop app;
* optionally compiles the firmware with the pinned ESP32 core (`BUILD_FIRMWARE=1`, about 1–2 GB to download).

```bash
(
set -euo pipefail
BUILD_FIRMWARE=0   # set to 1 to also install arduino-cli + the pinned ESP32 core and compile the firmware
# 1. Tools: Python venv support and curl (the only sudo step)
sudo apt-get update -y; sudo apt-get install -y python3-venv curl
# 1b. Node.js 22+ (Electron 44 needs >= 22.12): use the system one if new enough, else nvm in your home folder (no sudo)
NODE_MAJOR="$(node -p 'process.versions.node.split(".")[0]' 2>/dev/null || echo 0)"
if [ "$NODE_MAJOR" -lt 22 ]; then export NVM_DIR="$HOME/.nvm"; [ -s "$NVM_DIR/nvm.sh" ] || curl -fsSL https://raw.githubusercontent.com/nvm-sh/nvm/v0.40.8/install.sh | bash; set +u; . "$NVM_DIR/nvm.sh"; nvm install 22 >/dev/null; nvm use 22 >/dev/null; set -u; fi; echo "Node $(node -v), npm $(npm -v)"
# 2. Enter the project
cd ~/projects/ultrasonic-radar-scanner
# 3. Python environment for the site, generators and tests (CAD regeneration needs Python 3.11 - see README)
[ -x .venv/bin/python ] || python3 -m venv .venv; .venv/bin/python -m pip install -q --upgrade pip; .venv/bin/python -m pip install -q -r requirements-site.txt
# 4. Fast checks: equations, wiring/firmware sync, BOM, CAD report, app hardening, live-console parser
.venv/bin/python -m pytest -q tests; node --test tests/js/*.test.js
# 5. Build the web app (site/) and the desktop app's offline bundle (app/web/)
.venv/bin/python scripts/build_site.py; (cd app; npm ci --no-audit --no-fund; [ -f node_modules/electron/path.txt ] || node node_modules/electron/install.js; ../.venv/bin/python ../scripts/build_site.py --app --out web)
# 6. Optional: compile the firmware exactly as pinned in firmware/Radar_V6/sketch.yaml
if [ "$BUILD_FIRMWARE" = 1 ]; then mkdir -p ~/.local/bin; command -v arduino-cli >/dev/null || curl -fsSL https://raw.githubusercontent.com/arduino/arduino-cli/master/install.sh | BINDIR="$HOME/.local/bin" sh; PATH="$HOME/.local/bin:$PATH" arduino-cli compile --profile esp32-core3 --warnings all firmware/Radar_V6; fi
# 7. Serve the web app in the background (http://localhost:8000) and open the desktop app (close its window to finish)
(.venv/bin/python -m http.server 8000 -d site >/dev/null 2>&1 &) ; echo "Web app: http://localhost:8000   (stop later with: pkill -f 'http.server 8000')"
cd app; npx electron . || npx electron . --no-sandbox
)
```

* WSL: the desktop window opens through WSLg (Windows 11). The live console's serial link needs the
  **Windows** build of the app (or Chrome/Edge on Windows), because USB serial ports are not passed
  into WSL by default.
* Ubuntu 24.04+ on a real machine: if Electron exits with a sandbox message, the block retries with
  `--no-sandbox` (Ubuntu's AppArmor blocks Chromium's sandbox for apps run from a home folder). The
  same applies to the AppImage.
* Regenerating CAD (`scripts/render_cad.py`, `render_previews.py`) needs `requirements.txt`, which pins
  CadQuery for **Python 3.11**. If your Ubuntu ships a newer Python, make a 3.11 environment, for
  example `conda create -n radar python=3.11`, then `pip install -r requirements.txt`.

## Making the next release

1. Change the code and docs. Run the block-2 checks.
2. Bump `"version"` in `app/package.json` and add a matching `## x.y.z` entry at the top of `CHANGELOG.md`
   (a test enforces both).
3. `git commit -am "…" && git push && git tag -a vX.Y.Z -m "…" && git push origin vX.Y.Z`

The Release workflow refuses a tag that does not match `app/package.json`.

## After the first publish

* **Protect `main`:** Settings → Branches → require the `CI` checks.
* **Private vulnerability reporting:** Settings → Code security → enable it (see [`SECURITY.md`](SECURITY.md)).
* **Live link:** plug the scanner's own USB cable into the computer and open the live console ([`LIVE_LINK.md`](LIVE_LINK.md)).

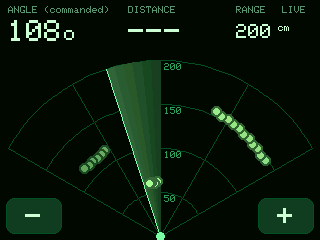
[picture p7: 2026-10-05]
hardware/diagrams/screen_texture.png

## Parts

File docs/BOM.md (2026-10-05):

# Bill of materials (BOM) — Radar V6

Parts kit

**Five things to buy, one optional.** No battery, charger, fuse, switch, breadboard, resistors
or screws beyond the two that come with the servo. Spreadsheet: [`manufacturing/bom.csv`](../manufacturing/bom.csv).

Prices are **rough single-unit marketplace estimates (US$, late 2026)** to show the order of
magnitude — not quotes. Check current listings yourself.

## Electronics

| # | Qty | Part | What to check before you buy | Reference candidate | Est. US$ |
|---|---|---|---|---|---|
| E1 | 1 | **ESP32-2432S028R "Cheap Yellow Display" (CYD)** — ESP32 + 2.8" 320×240 touch screen | Exact name `ESP32-2432S028R`. Both the ILI9341 version and the two-USB "CYD2USB" (ST7789) version work — the firmware detects the panel. | [witnessmenow/ESP32-Cheap-Yellow-Display](https://github.com/witnessmenow/ESP32-Cheap-Yellow-Display) | 12–20 |
| E2 | 1 | **Ultrasonic sensor, 3.3 V capable**: RCWL-1601 or HC-SR04P | Listing must say it works from **3 V–5.5 V**. A plain 5 V-only HC-SR04 needs the [fallback divider](WIRING.md#fallback-you-only-have-a-5-v-hc-sr04). | [Adafruit 4007](https://www.adafruit.com/product/4007) (RCWL-1601) | 2–4 |
| E3 | 1 | **SG90 micro servo, positional (180°)**, with horns and its 2 screws | **Not** "360°" or "continuous rotation". The single-arm horn must come in the bag. | TowerPro SG90 | 2–3 |
| E4 | 3 | **JST 1.25 mm 4-pin → Dupont female cable** | Often one is in the CYD box — you need three (CN1, P3, P1). | "1.25 mm 4 pin to Dupont" | 1–2 |
| E5 | 3 | **Male-male Dupont jumper pins** (or 3 short male-male jumpers) | Join the servo plug to the cable. | any | < 1 |
| E6 | 1 (optional) | 470–1000 µF, ≥ 6.3 V electrolytic capacitor | Only if the board resets when the servo moves. | any | < 1 |

You also need a **USB cable** that fits your CYD (micro-USB, or USB-C on CYD2USB boards) with data
lines for flashing, and a **USB charger or power bank rated ≥ 1 A**. Most people already have both.

**Estimated total: about US$18–30** for E1–E5 plus ≈ 120 g of PLA.

## Printed parts

| Part | Plate | Notes |
|---|---|---|
| 05 fit coupon | S1 | print first (≈ 10 cm³) — checks pegs, sensor holes, servo pilots |
| 01 shell | P1 | roof-down, no supports |
| 02 bezel | P2 | face-down |
| 03 base | P2 | flat |
| 04 head | P2 | face-down |

Sizes, volumes and PLA estimates: [`manufacturing/printed_parts.csv`](../manufacturing/printed_parts.csv).
Settings: [`PRINTING.md`](PRINTING.md).

## Fasteners

<!-- FASTENERS:BEGIN -->
| Qty | Item | Used for |
|---|---|---|
| 2 | self-tapping screws that come with the SG90 | servo flange → the two bosses under the roof |
| 1 | small screw that comes with the SG90 horn (optional) | horn → head foot, only if the press fit is loose |
<!-- FASTENERS:END -->

## Tools

Small Phillips screwdriver, side cutters, a multimeter (to check P1 VIN before connecting the
servo), and a 3D printer with a ≥ 105 × 100 mm bed (made for a Bambu Lab A1 mini, 180 × 180 mm).

## What V6 removed (and why it is cheaper)

| V5.1 needed | V6 |
|---|---|
| ESP32 DevKit + separate 1.8" LCD + 8 display wires | one CYD board (screen, touch, ESP32, RGB LED, USB) |
| 18650 cell, holder, charger/boost board, USB-C breakout, fuse, switch, 1000 µF capacitor | one USB cable from a charger or power bank |
| 2.2 kΩ + 3.3 kΩ divider | 3.3 V sensor — no divider |
| M2 screws, nuts, standoffs | press fits + the servo's own screws |
| 20 purchased line items, 28 wires, six printed parts | 5 line items, 7 wires, four printed parts |

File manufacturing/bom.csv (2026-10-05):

id | category | qty | part | check_before_buying | reference_candidate | est_usd | needed_from_stage | optional
E1 | Electronics | 1 | ESP32-2432S028R "Cheap Yellow Display" (CYD) — ESP32 + 2.8" 320×240 touch screen | Exact name ESP32-2432S028R. Both the ILI9341 version and the two-USB "CYD2USB" (ST7789) version work — the firmware detects the panel. | witnessmenow/ESP32-Cheap-Yellow-Display | 12–20 | 2 | no
E2 | Electronics | 1 | Ultrasonic sensor, 3.3 V capable: RCWL-1601 or HC-SR04P | Listing must say it works from 3 V–5.5 V. A plain 5 V-only HC-SR04 needs the fallback divider. | Adafruit 4007 (RCWL-1601) | 2–4 | 2 | no
E3 | Electronics | 1 | SG90 micro servo, positional (180°), with horns and its 2 screws | Not "360°" or "continuous rotation". The single-arm horn must come in the bag. | TowerPro SG90 | 2–3 | 2 | no
E4 | Cables | 3 | JST 1.25 mm 4-pin → Dupont female cable | Often one is in the CYD box — you need three (CN1, P3, P1). | "1.25 mm 4 pin to Dupont" | 1–2 | 2 | no
E5 | Cables | 3 | Male-male Dupont jumper pins (or 3 short male-male jumpers) | Join the servo plug to the cable. | any | < 1 | 2 | no
E6 | Optional | 1 | 470–1000 µF, ≥ 6.3 V electrolytic capacitor | Only if the board resets when the servo moves. | any | < 1 | 5 | yes
F1 | Fasteners (included with the servo) | 2 | self-tapping screws that come with the SG90 | servo flange → the two bosses under the roof | SG90 accessory bag | 0 | 4 | no
F2 | Fasteners (included with the servo) | 1 | small screw that comes with the SG90 horn (optional) | horn → head foot, only if the press fit is loose | SG90 accessory bag | 0 | 4 | yes

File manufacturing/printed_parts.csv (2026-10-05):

part | role | plate | print_size_mm | solid_volume_cm3 | pla_g_upper_bound | orientation | stl | step
01_shell | required | P1 | 104.0 x 94.9 x 62.0 | 51.8 | 64.2 | roof on the plate; 45-degree chamfers, no supports | cad/stl/01_shell.stl | cad/step/01_shell.step
02_bezel | required | P2 | 100.7 x 59.6 x 8.4 | 8.7 | 10.8 | viewer face on the plate; pegs up | cad/stl/02_bezel.stl | cad/step/02_bezel.step
03_base | required | P2 | 99.5 x 90.1 x 7.4 | 22.8 | 28.3 | flat; rim up | cad/stl/03_base.stl | cad/step/03_base.step
04_head | required | P2 | 56.0 x 39.5 x 20.0 | 10.5 | 13.0 | face on the plate; neck and foot lie flat | cad/stl/04_head.stl | cad/step/04_head.step
05_fit_coupon | print first - test piece | S1_fit_coupon | 92.0 x 42.0 x 9.0 | 9.7 | 12.0 | flat; print this first | cad/stl/05_fit_coupon.stl | cad/step/05_fit_coupon.step

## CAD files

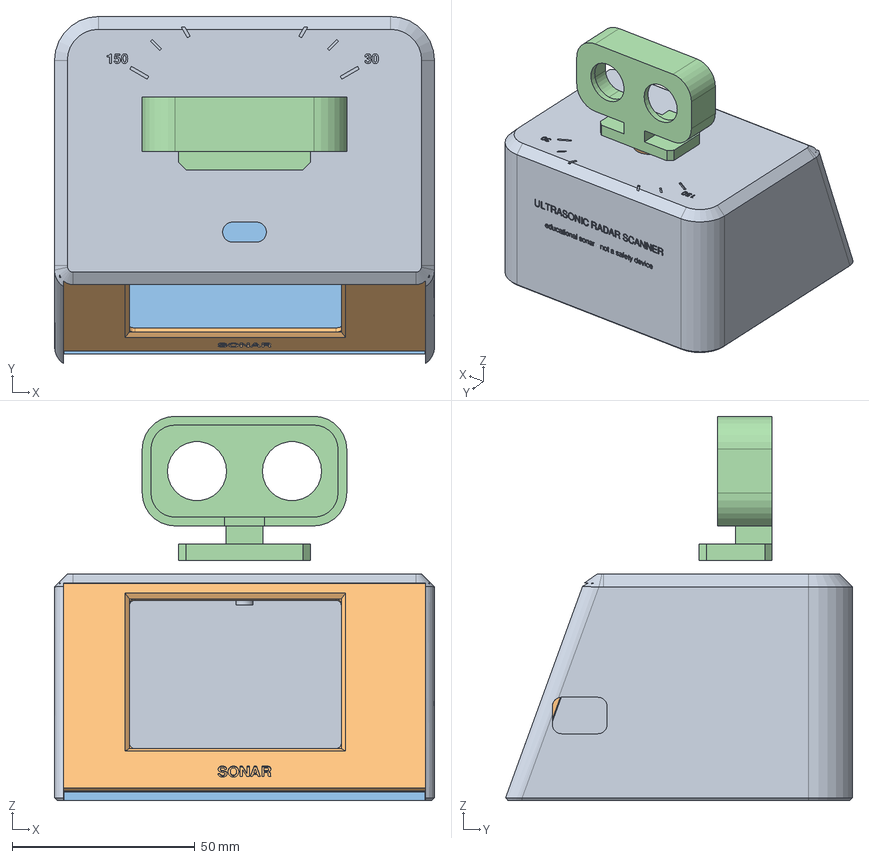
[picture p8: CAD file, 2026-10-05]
cad/step/assembly.step
104.0 x 94.9 x 105.2 mm
01_shell
02_bezel
03_base
04_head

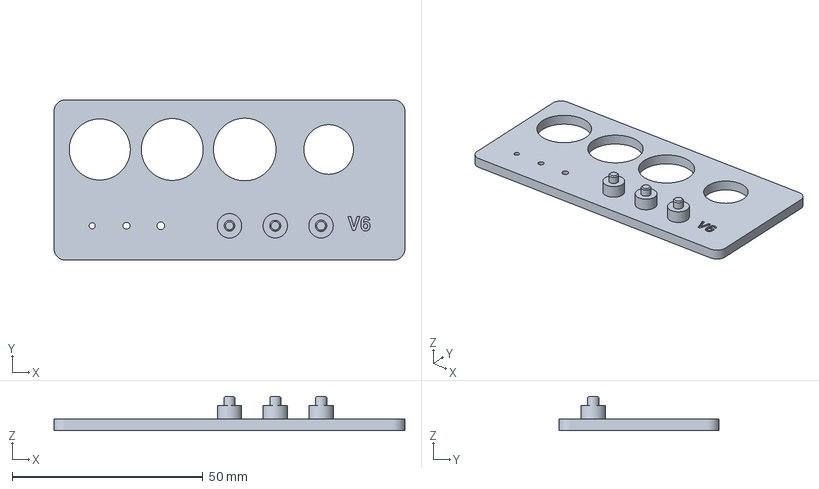
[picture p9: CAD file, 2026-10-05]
cad/3mf/plate_S1_fit_coupon.3mf
92.0 x 42.0 x 8.99 mm

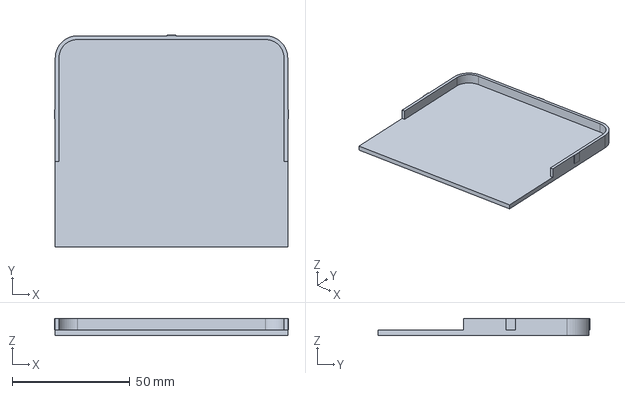
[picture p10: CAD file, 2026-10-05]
cad/step/03_base.step
99.5 x 90.1 x 7.40 mm

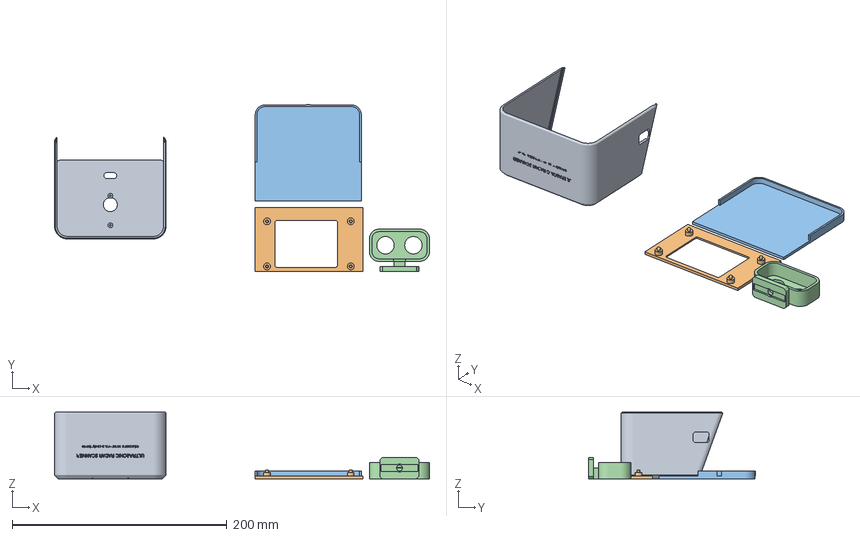
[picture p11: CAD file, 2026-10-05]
cad/3mf/radar_a1mini_multiplate.3mf
349.4 x 155.7 x 62.0 mm
01_shell
02_bezel
03_base
04_head

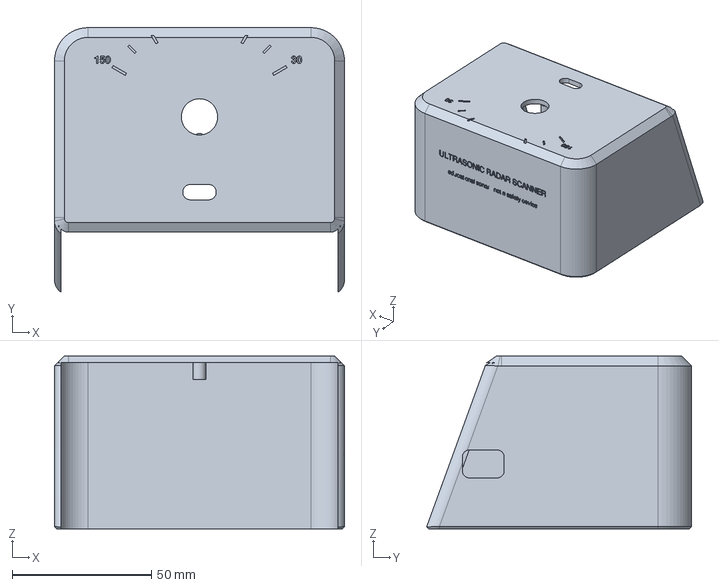
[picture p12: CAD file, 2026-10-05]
cad/step/01_shell.step
104.0 x 94.9 x 62.0 mm

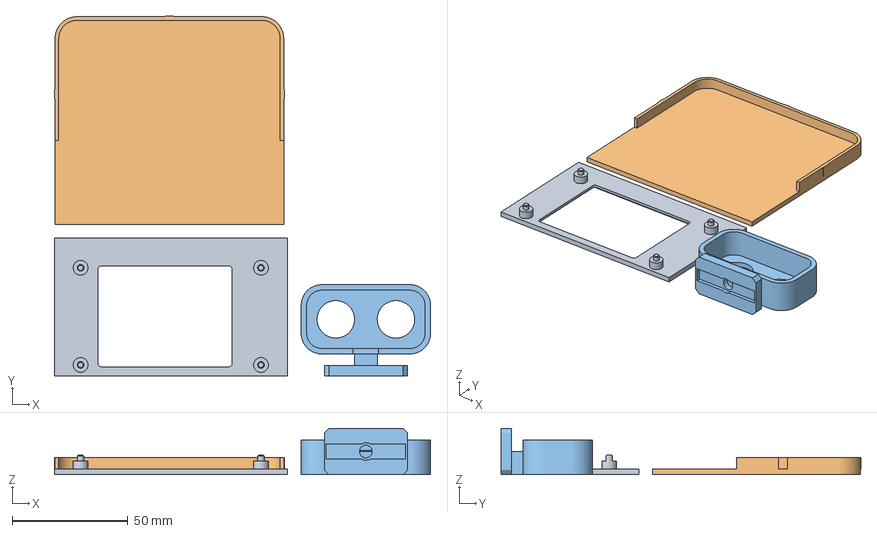
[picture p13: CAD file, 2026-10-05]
cad/3mf/plate_P2.3mf
162.7 x 155.7 x 20.0 mm
02_bezel
03_base
04_head

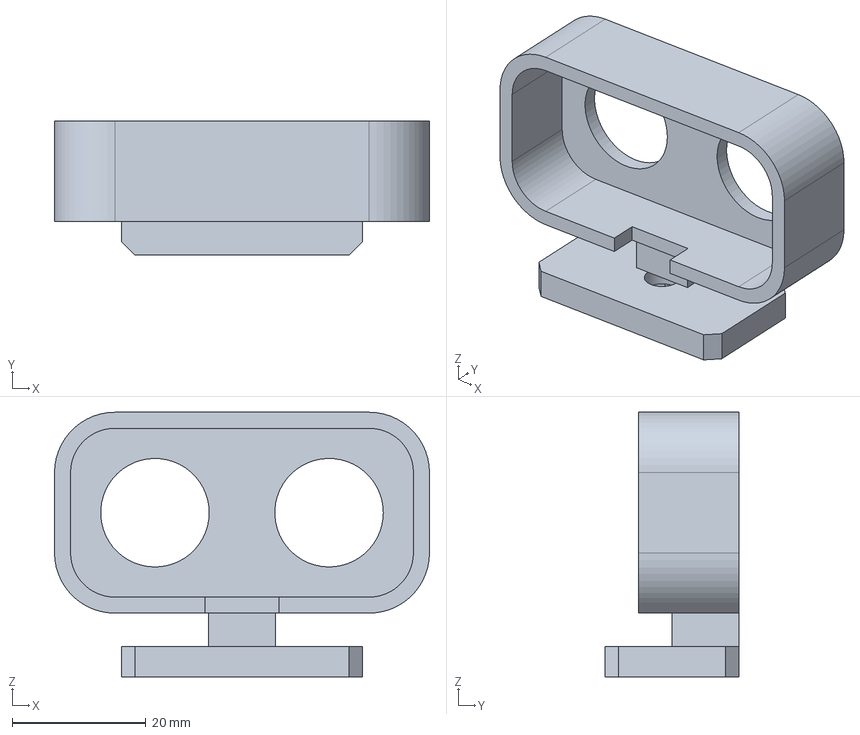
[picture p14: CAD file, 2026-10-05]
cad/step/04_head.step
56.0 x 20.0 x 39.5 mm

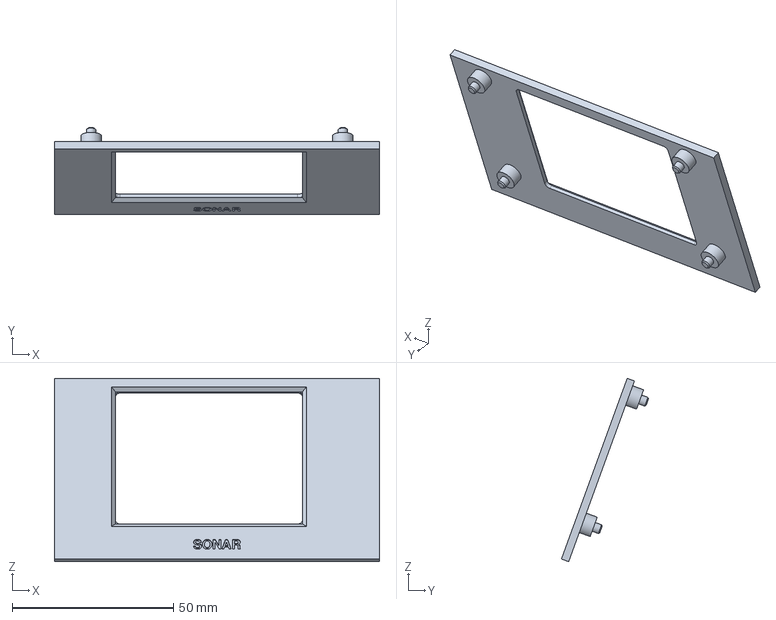
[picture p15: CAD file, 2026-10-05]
cad/step/02_bezel.step
100.7 x 27.0 x 56.8 mm

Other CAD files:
cad/3mf/plate_P1.3mf
cad/step/05_fit_coupon.step
cad/stl/01_shell.stl
cad/stl/02_bezel.stl
cad/stl/03_base.stl
cad/stl/04_head.stl
cad/stl/05_fit_coupon.stl

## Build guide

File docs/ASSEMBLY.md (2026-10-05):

# Assembly — about 30 minutes

Exploded render

Status: **not yet assembled by anyone** — this is the intended procedure. Record what happens in
[`VALIDATION.md`](VALIDATION.md); the [build packet](../manufacturing/build_packet.pdf) has the same
steps with tick boxes.

You need: the four printed parts, the CYD, the sensor, the SG90 (with its horn and two screws), three
JST-to-Dupont cables, three male-male pins, a small Phillips screwdriver and a USB cable.

Build stages

## 1 · Fit coupon

Print `plate_S1_fit_coupon.3mf` and choose the peg, sensor-hole and screw-pilot sizes
([Printing](PRINTING.md#the-fit-coupon)).

## 2 · Bench test before printing the rest

1. Wire the seven wires on the table ([Wiring](WIRING.md)) — USB unplugged.
2. Before the servo is connected, plug in USB and measure **P1 VIN ≈ 5 V** to GND (T-PWR-1). Unplug.
3. Connect the servo, plug in USB and flash: the **Flash** page in Chrome/Edge, or
   `arduino-cli compile --upload --profile esp32-core3 -p <port> firmware/Radar_V6`.
4. You should see the splash "EDU SONAR … NOT a safety device", then the green fan and the sweep.
   Touch **−** / **+** (bottom corners) to change the range; tap the fan to pause.
5. Point the sensor at a wall at a known distance and compare (T-FW-5).

**Wrong picture?** Open the serial monitor (115 200 baud): the `# board … panel …` line says which
display driver was detected. Then, in `firmware/Radar_V6/Radar_V6.ino`:

| Symptom | Setting |
|---|---|
| garbled or blank | `PANEL = PANEL_ILI9341` or `PANEL_ST7789` instead of `PANEL_AUTO` |
| colours inverted (black is white) | `INVERT_OVERRIDE = 0` or `1` |
| red looks blue | `SWAP_RED_BLUE = true` |
| glitches or stripes | `TFT_SPI_HZ = 27000000` |
| board resets when the servo starts | better charger (≥ 1 A), then the optional capacitor |

## 3 · Print

Plates P1 and P2, no supports ([Printing](PRINTING.md)).

## 4 · Assemble

Section through the assembled scanner

1. **Servo.** With the shell upside down, hold the SG90 against the two bosses under the roof, output
   shaft up through the turret hole, and fix it with **its own two screws**.
2. **Centre it.** Flash once with `CENTER_ONLY = true`: the servo holds 90°.
3. **Sensor into the head.** Press the two transducer cans into the head's holes from behind
   (pins towards the neck). Plug the four sensor wires on and feed them down through the slot next
   to the turret hole. Leave a loop of about 60 mm so the head can turn ±60° without tugging.
4. **Head onto the servo.** Press the single-arm horn into the slot in the head's foot, then press the
   horn onto the servo spline with the head **facing straight away from the screen**. The small horn
   screw is optional.
5. **Screen.** Press the CYD onto the four pegs on the back of the bezel, screen through the window,
   USB socket towards the shell's side opening.
6. **Bezel in.** Slide the bezel down into the grooves in the shell's front opening.
7. **Cables.** Plug the three cables into CN1, P3 and P1 and check them against the [net list](WIRING.md).
8. **Base.** Press the base into the bottom of the shell; its rim locks the bezel.
9. **Run.** Flash again with `CENTER_ONLY = false`. If the screen sweeps the opposite way to the head,
   set `REVERSE_SERVO = true`.

## 5 · Calibrate and record

Set `CALIBRATE_SERVO = true`: the head steps 30° → 90° → 150° with 4 s holds and prints each pulse
width. Compare with the ticks engraved on the roof and nudge `SERVO_US_AT_0` / `SERVO_US_AT_180` in
small steps. If the servo buzzes or strains at an end, back off. Set it back to `false`, then fill in
the test sheet (T-CAL-1, T-SWP-1, T-PWR-2, T-THM-1).

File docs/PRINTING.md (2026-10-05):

# Printing

Target printer: **Bambu Lab A1 mini** (180 × 180 × 180 mm), 0.4 mm nozzle, PLA. Any printer with a
bed of at least 110 × 105 mm can print every part one at a time from `cad/stl/`.

Status: plates, orientations and overhangs are **checked on screen only** ([`VALIDATION.md`](VALIDATION.md)).
Nothing has been printed yet.

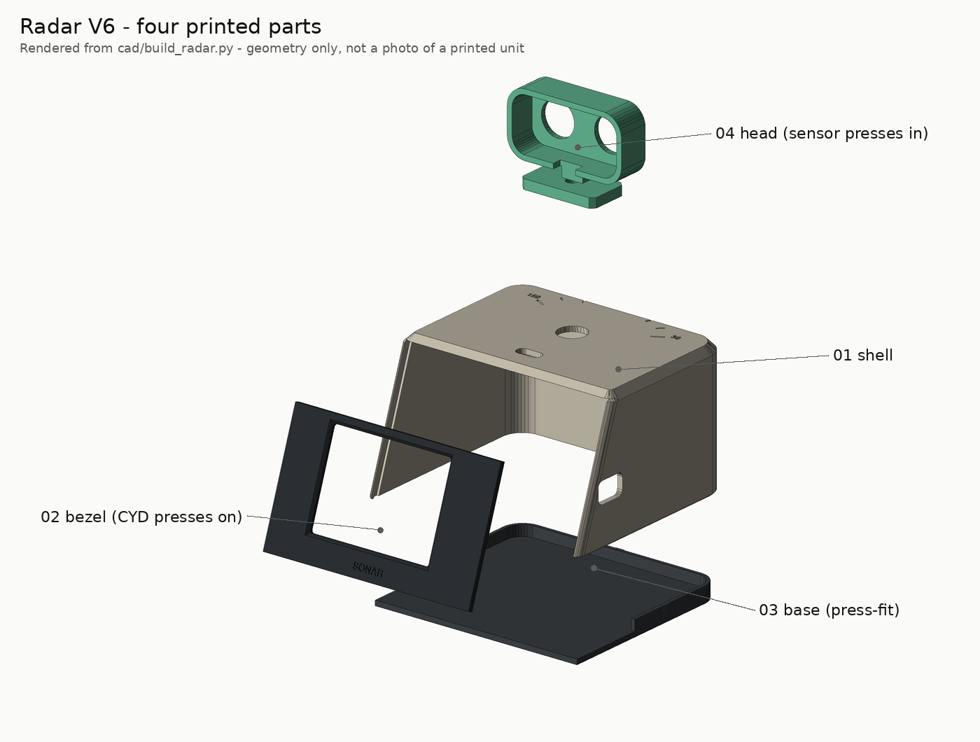
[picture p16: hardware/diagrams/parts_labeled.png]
Four printed parts


## Which file do I open?

| File | What it is | When |
|---|---|---|
| `cad/3mf/plate_S1_fit_coupon.3mf` | fit coupon (≈ 20 min) | **first** |
| `cad/3mf/radar_a1mini_multiplate.3mf` | **one file, two plates**: P1 shell, P2 bezel + base + head | after the coupon passes |
| `cad/3mf/plate_P1.3mf`, `plate_P2.3mf` | the same plates as plain 3MF | if the multi-plate file opens as one plate |
| `cad/stl/*.stl` | each part alone, already in print orientation | any slicer |
| `cad/step/*.step` | each part in its assembled position, plus `assembly.step` | editing in other CAD tools |

The multi-plate file carries Bambu-style plate metadata written by `scripts/render_cad.py`; it has
**not** been opened in Bambu Studio yet.

| Plate P1 | Plate P2 | Plate S1 |
|---|---|---|
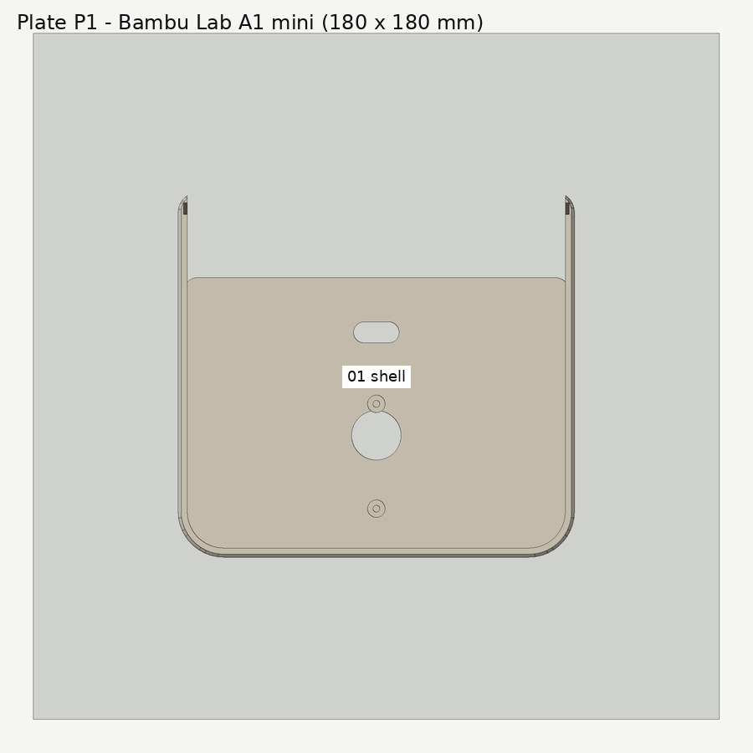
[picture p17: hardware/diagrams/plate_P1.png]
P1
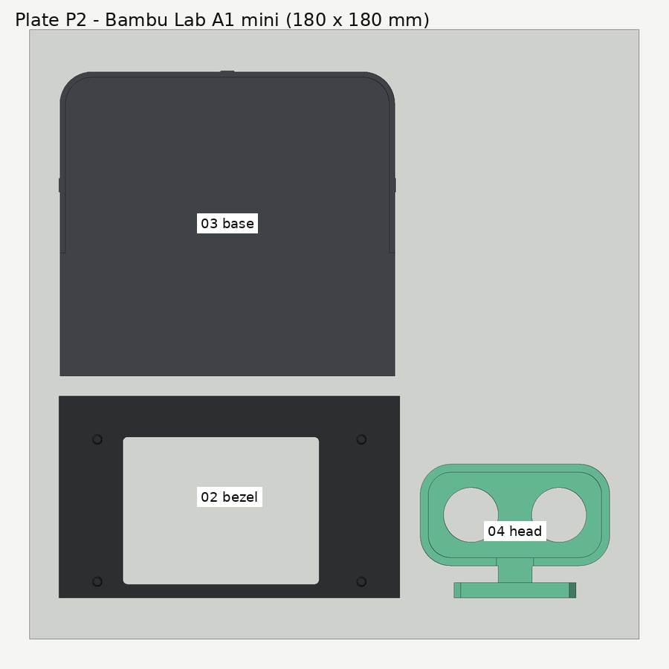
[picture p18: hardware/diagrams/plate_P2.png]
P2
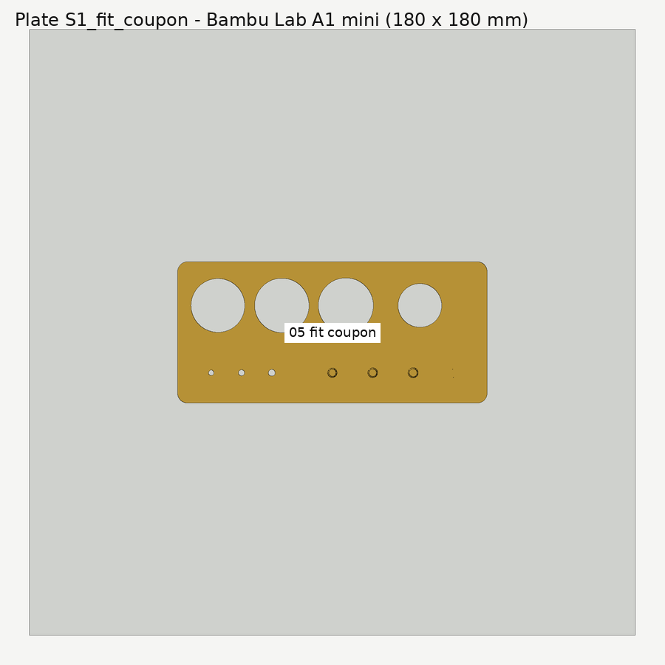
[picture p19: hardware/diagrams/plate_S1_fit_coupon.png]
S1
|  |  |  |

## Slicer settings (starting point)

| Setting | Value |
|---|---|
| Layer height | 0.20 mm |
| Walls | 3 (pegs and screw bosses need solid material) |
| Top / bottom layers | 5 / 4 |
| Infill | 15 % gyroid |
| Supports | **off** — every overhang is a 45° chamfer or a short bridge |
| Brim | only if your bed adhesion is marginal (shell) |

**Colours (suggestion):** shell in ivory or white, bezel and base in black or charcoal, head in mint
or any bright colour. One colour works too.

## Orientation (already applied in every STL / 3MF)

| Part | On the plate | Note |
|---|---|---|
| 01 shell | **roof down** | the roof chamfers are 45°; the engraved angle scale prints in the first layers |
| 02 bezel | viewer face down | the four CYD pegs point up |
| 03 base | flat, rim up | three small crush ribs on the rim give the press fit |
| 04 head | face down | neck and foot lie flat |
| 05 coupon | flat | |

## The fit coupon

Print it, then try your real parts in each hole and write the size that works into
`cad/build_radar.py` before printing the rest (`python scripts/render_cad.py` regenerates every file).

| Feature | Sizes | Pick the one where… | Variable |
|---|---|---|---|
| CYD pegs | 2.8 / 2.9 / 3.0 mm | the board's mounting hole presses on and stays | `PEG_D` |
| Sensor-can holes | 16.0 / 16.2 / 16.4 mm | a can presses in and holds | `CAN_HOLE_D` |
| Servo-screw pilots | 1.6 / 1.8 / 2.0 mm | the SG90's own screw bites without splitting | `PILOT_D` |

PLA: ≈ 95 cm³ solid for the four parts (upper bound ≈ 120 g; real use is lower with 15 % infill).

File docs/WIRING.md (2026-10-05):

# Wiring — 7 wires, pin by pin (Radar V6)

Wiring picture

> **Follow the silkscreen labels, not the wire colours.** Cable colours and the pin order printed
> on Cheap Yellow Display (CYD) connectors differ between batches. Read the labels on *your* board
> before plugging anything in.

This page is the **single source of truth**. `python scripts/gen_diagrams.py` draws the diagrams
from the tables below, and `python -m pytest tests/test_sync.py` fails if the firmware `PIN_…`
constants disagree with them.

Status: **checked on paper only** — nothing here has been wired and powered yet
([`VALIDATION.md`](VALIDATION.md)).

## The three connectors you use

The CYD has three small 4-pin **JST 1.25 mm** sockets on its back. You use one or two pins on each.

| Connector | Its 4 pins (typical silkscreen) | You use |
|---|---|---|
| **CN1** | GND · IO22 · IO27 · 3.3V | all four: sensor power, TRIG, ground + servo signal |
| **P3** | GND · IO35 · IO22 · IO21 | **IO35 only** (sensor ECHO). Leave IO22 and IO21 unconnected (IO21 is the backlight on most boards). |
| **P1** | VIN · TX · RX · GND | **VIN and GND only** (servo power). Leave TX/RX alone — they are the USB serial lines. |

## Net list (machine-readable)

One row per wire end. `Wire` is the label to put on each wire.

<!-- NETLIST:BEGIN -->
| ID | Wire | Pin | Net | Kind | Notes |
|---|---|---|---|---|---|
| N01 | W1 | CN1.3V3 | 3V3 | POWER | 3.3 V from the CYD regulator |
| N02 | W1 | SENSOR.VCC | 3V3 | POWER | RCWL-1601 / HC-SR04P runs at 3.3 V |
| N03 | W2 | CN1.IO27 | TRIG | SIGNAL | 10 µs trigger pulse |
| N04 | W2 | SENSOR.TRIG | TRIG | SIGNAL |  |
| N05 | W3 | P3.IO35 | ECHO | SIGNAL | input-only pin; 3.3 V echo, no divider |
| N06 | W3 | SENSOR.ECHO | ECHO | SIGNAL |  |
| N07 | W4 | CN1.GND | GND | POWER | common ground |
| N08 | W4 | SENSOR.GND | GND | POWER |  |
| N09 | W5 | CN1.IO22 | SERVO_PWM | SIGNAL | 50 Hz pulses, 1000–2000 µs |
| N10 | W5 | SERVO.SIGNAL | SERVO_PWM | SIGNAL | orange (or yellow/white) lead |
| N11 | W6 | P1.VIN | VIN_5V | POWER | USB 5 V on the board side. VERIFY on your board |
| N12 | W6 | SERVO.+5V | VIN_5V | POWER | red lead (middle) |
| N13 | W7 | P1.GND | GND | POWER | same copper as CN1.GND |
| N14 | W7 | SERVO.GND | GND | POWER | brown (or black) lead |
<!-- NETLIST:END -->

## Firmware pin map

`Where` says how you reach the pin: a connector, or `on-board` (already wired on the CYD, nothing to do).

<!-- PINMAP:BEGIN -->
| Firmware constant | GPIO | Where | Direction | Function |
|---|---|---|---|---|
| PIN_TRIG | 27 | CN1 | output | sensor trigger |
| PIN_ECHO | 35 | P3 | input | sensor echo (input-only pin) |
| PIN_SERVO | 22 | CN1 | output | servo PWM (LEDC, 50 Hz) |
| PIN_TFT_SCK | 14 | on-board | output | display SPI clock |
| PIN_TFT_MISO | 12 | on-board | input | display SPI data in |
| PIN_TFT_MOSI | 13 | on-board | output | display SPI data out |
| PIN_TFT_CS | 15 | on-board | output | display chip select |
| PIN_TFT_DC | 2 | on-board | output | display data/command |
| PIN_TFT_BL | 21 | on-board | output | backlight |
| PIN_TOUCH_CLK | 25 | on-board | output | touch SPI clock |
| PIN_TOUCH_MISO | 39 | on-board | input | touch SPI data in |
| PIN_TOUCH_MOSI | 32 | on-board | output | touch SPI data out |
| PIN_TOUCH_CS | 33 | on-board | output | touch chip select |
| PIN_TOUCH_IRQ | 36 | on-board | input | touch interrupt |
| PIN_LED_R | 4 | on-board | output | RGB LED red (active low) |
| PIN_LED_G | 16 | on-board | output | RGB LED green (active low) |
| PIN_LED_B | 17 | on-board | output | RGB LED blue (active low) |
<!-- PINMAP:END -->

## Step by step

1. **Unplug USB.** Never wire with the board powered.
2. **CN1 cable → sensor + servo signal.** 3.3V → `VCC`, IO27 → `Trig`, GND → `Gnd`, IO22 → servo signal.
3. **P3 cable → sensor echo.** IO35 → `Echo`. Tape off the other three wires of that cable.
4. **P1 cable → servo power.** VIN → servo red, GND → servo brown. Tape off TX and RX.
5. Route the sensor's four wires up through the slot next to the turret hole and leave a loop
   so the head can turn ±60°.
6. Check every wire against the net list above before connecting USB.

The servo plug and the CYD cables often both end in *female* Dupont sockets: join them with
three male-to-male jumper pins, or crimp/solder and heat-shrink.

## Power — read this

* The scanner runs from **one USB cable**. Use a phone charger or power bank rated **≥ 1 A**.
  A laptop port (often 500 mA) may brown out when the servo starts.
* The servo is fed from P1 **VIN**. On the boards documented by the community this pin is the
  USB 5 V rail (through the board's protection parts). **VERIFY with a multimeter** on your board
  before connecting the servo: you should read ≈ 4.5–5.2 V between P1 VIN and GND with USB in.
* If the screen flickers or the board resets when the servo moves, add a **470–1000 µF, ≥ 6.3 V
  electrolytic capacitor** across the servo's red (+) and brown (−) leads, stripe to brown.

## Fallback: you only have a 5 V HC-SR04

A classic HC-SR04 (not the "P" version) needs 5 V and outputs a **5 V echo** that can damage the
ESP32. If that is what you have:

* Power it from **P1 VIN** instead of CN1 3.3V.
* Put a divider in the echo line: `ECHO —[2.2 kΩ]— IO35`, and `IO35 —[3.3 kΩ]— GND`
  (5 V × 3.3/5.5 ≈ 3.0 V).

The RCWL-1601 / HC-SR04P costs about the same and needs neither, which is why it is the default.

## Programming

Plug the CYD into your computer by USB and flash from the web page (`flash.html`) or with
`arduino-cli` ([`README`](../README.md#flash)). The sensor and servo can stay connected.
Spreadsheet versions: [`manufacturing/wiring_pins.csv`](../manufacturing/wiring_pins.csv) and
[`manufacturing/wire_list.csv`](../manufacturing/wire_list.csv).

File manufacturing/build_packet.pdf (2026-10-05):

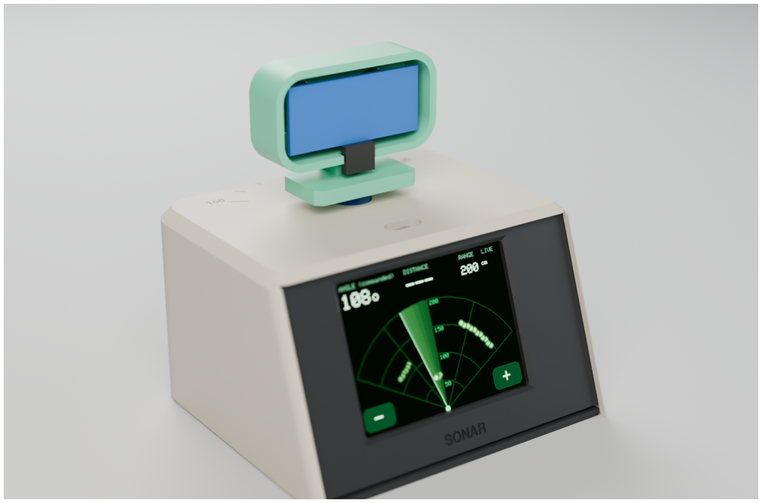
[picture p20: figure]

Ultrasonic Radar Scanner · Radar V6 build packet · release 6.0.0 · educational sonar — not a safety device | page 1

# Ultrasonic Radar Scanner

Build packet — Radar V6 “Mini” · repository release 6.0.0 · generated 2026-10-04

Honest scope. An educational ultrasonic (sonar) instrument with a radar-style display — not radio-frequency radar and not a safety, obstacle-avoidance or people-detection device. It sweeps about 120°; the angle shown is the commanded servo position. At the time this packet was generated, no unit had been printed, wired or powered — your build is part of the validation.

Unit / serial

Builder

Start date

Printer + filament

Firmware (version / SHA-256)

Notes

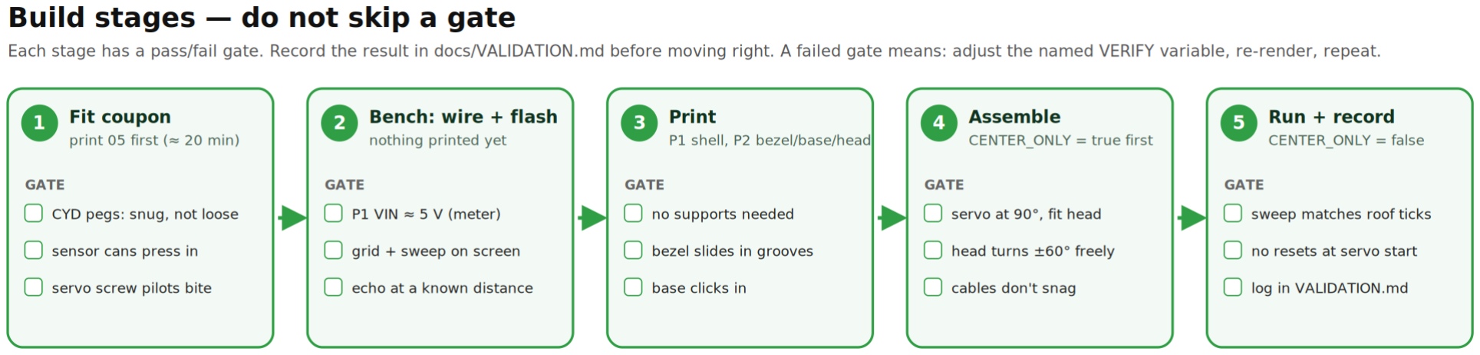
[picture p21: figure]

Ultrasonic Radar Scanner · Radar V6 build packet · release 6.0.0 · educational sonar — not a safety device | page 2

# 1 · Safety rules (read before wiring)

☐ Wire only with USB unplugged. Check every wire against the list before plugging in.
☐ Use a 3.3 V-capable sensor (RCWL-1601 / HC-SR04P). A 5 V-only HC-SR04 needs the 2.2 kΩ / 3.3 kΩ divider on ECHO (docs/WIRING.md, fallback).
☐ Measure P1 VIN ≈ 5 V with a multimeter before connecting the servo to it.
☐ Leave P1 TX/RX and P3 IO21/IO22 unconnected.
☐ Power from a charger or power bank rated ≥ 1 A. Unplug if anything gets hot or smells.
☐ Keep fingers and hair clear of the turning head; it is a toy-grade servo, not a guarded mechanism.

## Build stages — each has a gate; record results before moving on

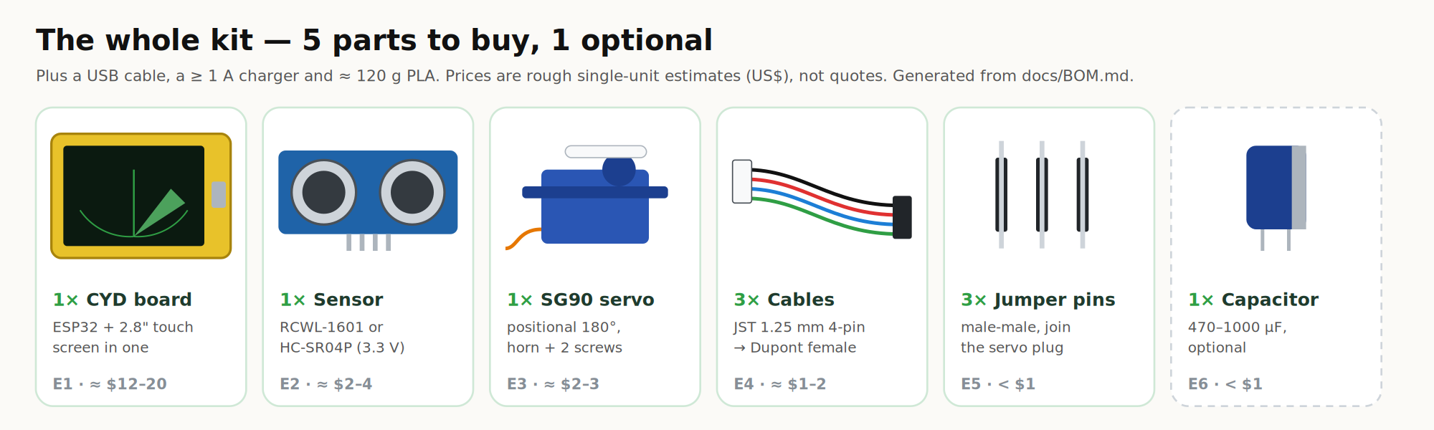
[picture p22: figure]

Ultrasonic Radar Scanner · Radar V6 build packet · release 6.0.0 · educational sonar — not a safety device | page 3

# 2 · Parts checklist

✓ | ID | Qty | Part | Check before you buy
☐ | E1 | 1 | ESP32-2432S028R "Cheap Yellow Display" (CYD) — ESP32 + 2.8" 320×240 touch screen | Exact name ESP32-2432S028R. Both the ILI9341 version and the two-USB "CYD2USB" (ST7789) version work — the firmware detects the panel.
☐ | E2 | 1 | Ultrasonic sensor, 3.3 V capable: RCWL-1601 or HC-SR04P | Listing must say it works from 3 V–5.5 V. A plain 5 V-only HC-SR04 needs the fallback divider.
☐ | E3 | 1 | SG90 micro servo, positional (180°), with horns and its 2 screws | Not "360°" or "continuous rotation". The single-arm horn must come in the bag.
☐ | E4 | 3 | JST 1.25 mm 4-pin → Dupont female cable | Often one is in the CYD box — you need three (CN1, P3, P1).
☐ | E5 | 3 | Male-male Dupont jumper pins (or 3 short male-male jumpers) | Join the servo plug to the cable.
☐ | E6 | 1 | 470–1000 µF, ≥ 6.3 V electrolytic capacitor | Only if the board resets when the servo moves.
☐ | F1 | 2 | self-tapping screws that come with the SG90 | servo flange → the two bosses under the roof
☐ | F2 | 1 | small screw that comes with the SG90 horn (optional) | horn → head foot, only if the press fit is loose


Ultrasonic Radar Scanner · Radar V6 build packet · release 6.0.0 · educational sonar — not a safety device | page 4

# 3 · Printed parts

Files: cad/3mf/ (Bambu A1 mini plates), cad/stl/ (already in print orientation), cad/step/ (editable). Print the fit coupon first and adjust any VERIFY value in cad/build_radar.py before the long prints. PLA, 0.20 mm layers, 3 walls, 15–20 % gyroid, no supports.

✓ | Part | Role | Plate | Print size (mm) | PLA ≤ g | Orientation
☐ | 01_shell | required | P1 | 104.0 x 94.9 x 62.0 | 64.2 | roof on the plate; 45-degree chamfers, no supports
☐ | 02_bezel | required | P2 | 100.7 x 59.6 x 8.4 | 10.8 | viewer face on the plate; pegs up
☐ | 03_base | required | P2 | 99.5 x 90.1 x 7.4 | 28.3 | flat; rim up
☐ | 04_head | required | P2 | 56.0 x 39.5 x 20.0 | 13.0 | face on the plate; neck and foot lie flat
☐ | 05_fit_coupon | print first - test piece | S1 | 92.0 x 42.0 x 9.0 | 12.0 | flat; print this first

## Fit coupon (stage 1)

✓ | Coupon test | Pass when | Size chosen
☐ | CYD pegs 2.8 / 2.9 / 3.0 mm | board presses on and stays; no cracking
☐ | Sensor can holes 16.0 / 16.2 / 16.4 mm | cans press in and hold, PCB not stressed
☐ | Servo screw pilots 1.6 / 1.8 / 2.0 mm | the SG90 screw bites and holds without splitting

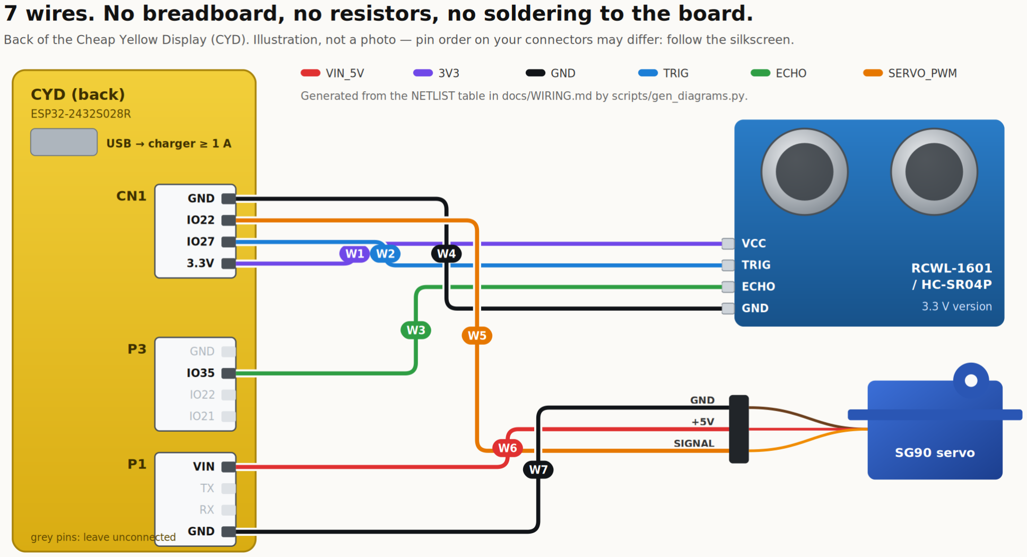
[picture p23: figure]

Ultrasonic Radar Scanner · Radar V6 build packet · release 6.0.0 · educational sonar — not a safety device | page 5

# 4 · Wiring — point to point

Cut, label and fit each wire, then tick it. Follow the labels on the modules, not wire colours. Seven wires; USB unplugged. Source of truth: docs/WIRING.md.

✓ | Wire | From | To | Net | Notes
☐ | W1 | CN1.3V3 | SENSOR.VCC | 3V3 | 3.3 V from the CYD regulator; RCWL-1601 / HC-SR04P runs at 3.3 V
☐ | W2 | CN1.IO27 | SENSOR.TRIG | TRIG | 10 µs trigger pulse
☐ | W3 | P3.IO35 | SENSOR.ECHO | ECHO | input-only pin; 3.3 V echo, no divider
☐ | W4 | CN1.GND | SENSOR.GND | GND | common ground
☐ | W5 | CN1.IO22 | SERVO.SIGNAL | SERVO_PWM | 50 Hz pulses, 1000–2000 µs; orange (or yellow/white) lead
☐ | W6 | P1.VIN | SERVO.+5V | VIN_5V | USB 5 V on the board side. VERIFY on your board; red lead (middle)
☐ | W7 | P1.GND | SERVO.GND | GND | same copper as CN1.GND; brown (or black) lead

Not connected on purpose: P1 TX/RX (USB serial), P3 GND/IO22/IO21, and the CYD's SD card and speaker. The servo plug and the cables often both end in female sockets — join them with male-male pins.


Ultrasonic Radar Scanner · Radar V6 build packet · release 6.0.0 · educational sonar — not a safety device | page 6

# 5 · Firmware

☐ Connect the CYD to the computer with a data-capable USB cable (sensor and servo may stay connected).
☐ EITHER open the web page → Flash firmware (Chrome/Edge) and install the release build, OR compile: arduino-cli compile --upload --profile esp32-core3 -p <port> firmware/Radar_V6.
☐ For assembly, first flash with CENTER_ONLY = true (servo holds 90°), then set it back to false.
☐ Splash shows “EDU SONAR … NOT a safety device”, then the green fan and the sweep.

# 6 · Assembly gates

## Stage 2 — bench (nothing printed yet)

☐ P1 VIN ≈ 5 V measured with USB in
☐ Grid, sweep and readings appear; touch −/+ changes range ☐ Echo at 30 / 100 / 150 cm recorded
☐ No resets when the servo starts (else add the capacitor)

## Stage 3 — print

☐ P1 shell and P2 bezel/base/head printed without supports ☐ Bezel slides into the shell grooves without forcing

## Stage 4 — assemble

☐ CYD pressed onto the bezel pegs, screen through the window
☐ Servo screwed under the roof with its own 2 screws
☐ CENTER_ONLY: horn pressed into the head foot, head facing the scan side ☐ Sensor cans pressed into the head; cable through the slot with slack
☐ Bezel slid in, base pressed in; USB socket reachable

## Stage 5 — run

☐ CENTER_ONLY = false; head sweeps 30°–150° without touching anything ☐ Screen direction matches the head (else REVERSE_SERVO)
☐ Roof ticks match the screen angle (CALIBRATE_SERVO)

Ultrasonic Radar Scanner · Radar V6 build packet · release 6.0.0 · educational sonar — not a safety device | page 7

# 7 · Physical test sheet

Copy results into docs/VALIDATION.md (or open a pull request) — that is how the design becomes
validated.
Test | What | Pass criterion | Result | Date / initials
T-PRN-1 | Print the fit coupon; try the CYD pegs, sensor-can holes and servo-screw pilots | chosen sizes recorded; PEG_D, CAN_HOLE_D, PILOT_D updated if needed
T-PRN-2 | Print P1 (shell, roof-down) | no supports, chamfers and grooves clean
T-PRN-3 | Print P2 (bezel, base, head) | no supports; pegs not snapped
T-FIT-1 | CYD pressed onto the bezel pegs | firm; screen centred in the window (else set CYD_VIEW_DX)
T-FIT-2 | Bezel slides into the shell grooves; base presses in; USB plug reaches the board | nothing forced; base stays in when lifted
T-FIT-3 | Servo screwed under the roof with its own screws; horn pressed into the head foot | head firm on the spline, no wobble
T-FIT-4 | Sensor cans pressed into the head | cans hold; PCB not bent
T-PWR-1 | P1 VIN voltage with USB in: idle, and while the servo moves | ≈ 4.5–5.2 V; record the dip
T-PWR-2 | One-hour run from a ≥ 1 A charger | no resets, flicker or brown-outs (else add the capacitor and re-test)
T-PWR-3 | Run from a laptop USB port | record whether it works; note resets
T-PWR-4 | Current draw with a USB meter: idle and sweeping | record mA
T-FW-1 | Flash; splash, then grid and sweep | as described in ASSEMBLY
T-FW-2 | Panel detection and colours (# board … panel … line) | correct picture; else record the PANEL / INVERT_OVERRIDE / SWAP_RED_BLUE that work
T-FW-3 | CENTER_ONLY head fit; REVERSE_SERVO direction | head faces straight out at 90°; screen matches head
T-FW-4 | Measured timing from the serial "# measured" line | record mean step and one-way sweep (estimate ≈ 115 ms, ≈ 4.6 s)
T-FW-5 | Distance at 30 / 100 / 150 cm on the 90° line (flat target) | record reading vs tape measure
T-FW-6 | Touch: − / + change the range; tap the fan to pause | each tap acts once; no false taps
T-FW-7 | RGB LED turns red under 30 cm | as described
T-CAL-1 | CALIBRATE_SERVO against the roof ticks without hitting the end stops | record SERVO_US_AT_0/180; no buzzing at ends
T-SWP-1 | Powered sweep with the sensor cable fitted | no rubbing, no cable tug at 30° or 150°
T-THM-1 | Temperatures after 30 min running (board regulator, servo) | nothing uncomfortable to touch
T-LNK-1 | Live console over the scanner's own USB cable at 115 200 baud | readings appear, sweep matches the head; note whether opening the port resets the board
T-LNK-2 | Record a session in the console and replay it | replay matches the live view
T-APP-1 | Windows installer + portable build open and connect | app opens; port picker lists the board
T-APP-2 | macOS build opens (after Gatekeeper approval) and connects | as above
T-FLS-1 | Browser flasher (Flash page, Chrome/Edge) installs the release firmware on a CYD | splash screen appears
T-REL-1 | First tagged release carries the source ZIP, manufacturing kit, firmware, desktop apps, SHA256SUMS and attestations | sha256sum -c and gh attestation verify pass

Ultrasonic Radar Scanner · Radar V6 build packet · release 6.0.0 · educational sonar — not a safety device | page 8

## Sign-off

All gates passed and recorded | ☐
Labelled “educational — not a safety device” | ☐

### Signature / date

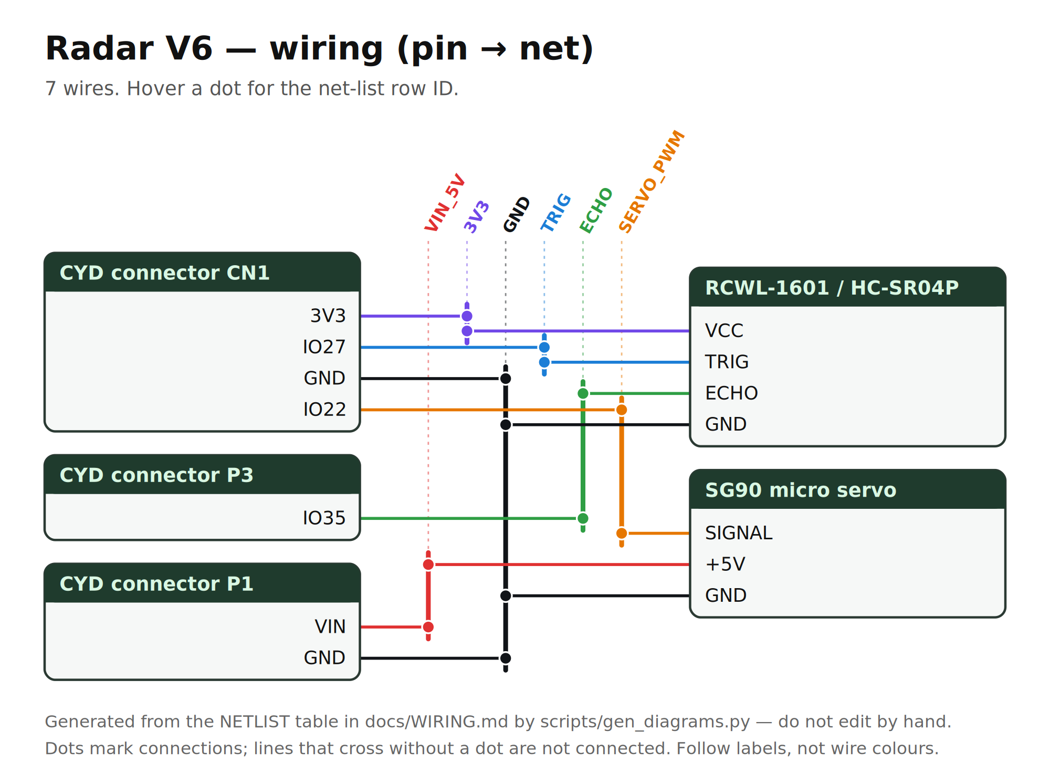
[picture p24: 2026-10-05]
hardware/diagrams/png/wiring_full.png

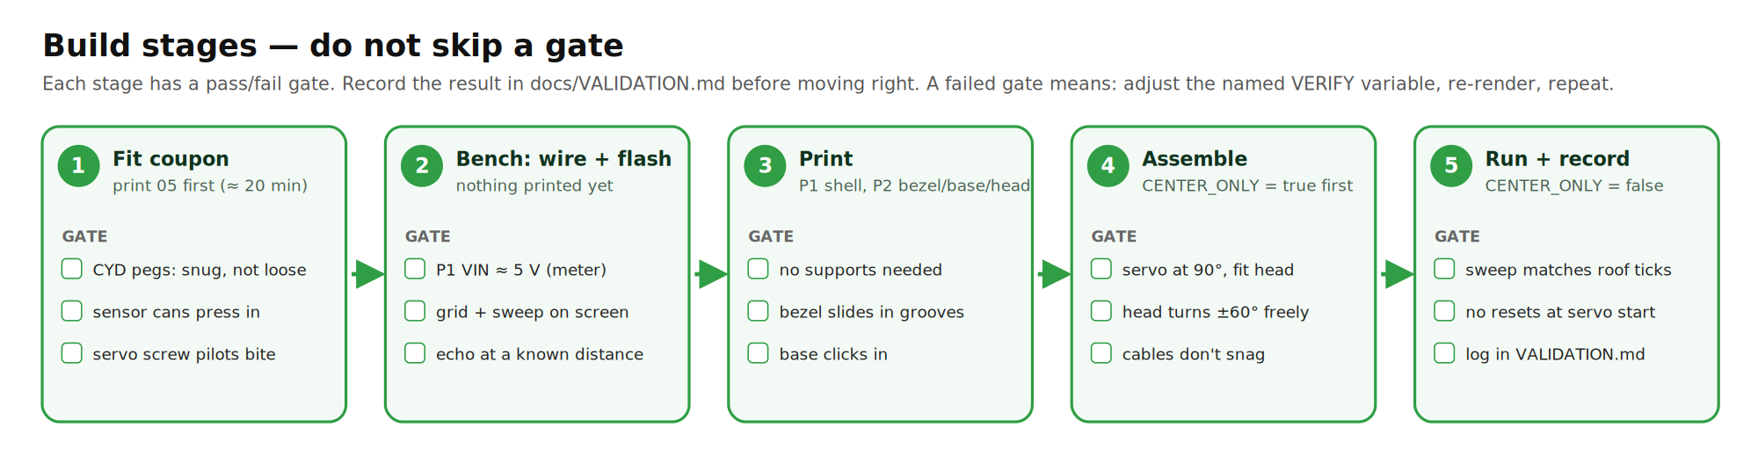
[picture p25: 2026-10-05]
hardware/diagrams/png/build_flow.png

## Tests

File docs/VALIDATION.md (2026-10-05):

# Validation log — what is known, and what is not

Two kinds of evidence, never mixed:

* **RECORDED** — checks a computer can run without hardware: CAD solids are valid, parts fit the
  bed and don't overlap in the model, the firmware compiles, the equations agree, the docs and
  firmware agree. Real results, but they say nothing about whether a physical build works.
* **PHYSICAL** — anything that needs a printer, a multimeter, a powered scanner or a tape measure.

> **Current status: no PHYSICAL validation has been performed for Radar V6.** No part has been
> printed or fitted, the firmware has not been flashed onto a Cheap Yellow Display, and the scanner
> has never been powered. Do not call it "working" until the PHYSICAL table has entries.

## RECORDED checks

| ID | Check | Result | Date (UTC) | Evidence / how to reproduce |
|---|---|---|---|---|
| R-CAD-1 | All 5 parts build as single valid solids; the shell matches its nominal size within 0.6 mm | PASS | 2026-10-04 | `python scripts/render_cad.py` → `cad/geometry_report.json` |
| R-CAD-2 | Every print mesh is watertight with outward normals | PASS | 2026-10-04 | same report |
| R-CAD-3 | Plates P1, P2 and S1 fit the A1 mini bed (180 × 180 mm, 6 mm margin), parts ≥ 6 mm apart | PASS | 2026-10-04 | same report, "plates" |
| R-CAD-4 | No overlap in the assembled model between printed parts and the module models (CYD, SG90, horn, sensor) — 14 pairs; the base's three 0.3 mm crush ribs are the only allowed overlap; the CYD sits on the bezel pegs | PASS | 2026-10-04 | same report, "interference" |
| R-CAD-5 | Sweep clearance in the model: head + sensor and horn rotated −75°…+75° (commanded travel is ±60°) never touch the shell or servo | PASS | 2026-10-04 | same report, "sweep" |
| R-CAD-6 | Designed clearances: horn foot 3.7 mm above the roof; screen glass 0.1 mm behind the bezel; CYD 1.8 mm from the shell, 19.4 mm from the servo | RECORDED | 2026-10-04 | same report, "clearances" — all depend on VERIFY values |
| R-FW-1 | Firmware compiles for ESP32 Dev Module on Arduino-ESP32 **3.3.12** with `--warnings all`: 0 warnings, 0 errors (334 227 B flash, 25 056 B RAM) | PASS | 2026-10-04 | [`validation/compile_core3.txt`](validation/compile_core3.txt) |
| R-FW-2 | Same sketch on Arduino-ESP32 **2.0.17** (the 2.x LEDC path): 0 warnings, 0 errors (304 621 B flash, 23 192 B RAM) | PASS | 2026-10-04 | [`validation/compile_core2.txt`](validation/compile_core2.txt) |
| R-FW-3 | 320 × 240 screen layout checked in the pixel-level Python port of the drawing code | PASS | 2026-10-04 | `python scripts/sim_display.py` → `hardware/diagrams/radar_frame.png` — synthetic targets only |
| R-EQ-1 | 19 equation checks: distance, temperature effect, echo timeout, 3.3 V echo level, fallback divider incl. worst case, LEDC duty, angle map, clamp, sweep cadence estimate, dot persistence | PASS | 2026-10-04 | `python -m pytest tests/test_equations.py` |
| R-SYNC-1 | Firmware pins = WIRING.md pin map = net list; 7 wires with two ends each; sensor on 3.3 V; servo on VIN; USB serial and backlight pins untouched; no flash pins, no strapping pins on the wires | PASS | 2026-10-04 | `python -m pytest tests/test_sync.py` |
| R-BOM-1 | BOM has 5 required items + 1 optional, no battery or loose screws, sensor must be 3.3 V capable, prices labelled as estimates | PASS | 2026-10-04 | `python -m pytest tests/test_bom.py` |
| R-APP-1 | Shared serial parser/recorder (web + desktop): 10 checks incl. the firmware's exact `printf` formats | PASS | 2026-10-04 | `node --test tests/js/*.test.js` |
| R-APP-2 | Web app in headless Chromium: simulator, wiring explorer, demo stream, record + save CSV, replay, guide images, service worker, offline reload, no page errors | PASS | 2026-10-04 | `python tests/browser/check_site.py` |
| R-APP-3 | Desktop app (Electron) run from source: every main page loads with no errors or broken images, offline KaTeX renders, Web Serial API present, demo delivers readings | PASS | 2026-10-04 | `xvfb-run npx electron . --smoke-test` |
| R-APP-4 | Linux installers built: AppImage + tar.gz (electron-builder) — from the V5.2 release build; Windows and macOS installers are built only by `.github/workflows/release.yml` and have **not** been run | RECORDED | 2026-10-02 | local build |
| R-MFG-1 | Manufacturing exports regenerate identically from the docs (BOM, printed parts, pin list, 7-wire list); every pin appears in the wire list; build packet PDF builds | PASS | 2026-10-04 | `python -m pytest tests/test_mfg.py`, `python scripts/make_build_packet.py` |
| R-REQ-1 | Every requirement has a verification method and evidence that exists here; every physical test traces to a requirement | PASS | 2026-10-04 | `python -m pytest tests/test_requirements.py` |
| R-FLS-1 | Browser-flasher payload: merged ESP32 image (offset 0x0) and ESP Web Tools manifest generated from the compiled firmware | PASS | 2026-10-04 | `python scripts/build_site.py --firmware …merged.bin`; flashing itself is T-FLS-1 |
| R-APP-5 | Electron hardening + listen-only console encoded as tests (context isolation, sandbox, no Node, permissions refused except serial, CSP, no serial writes) | PASS | 2026-10-04 | `python -m pytest tests/test_app.py` |

Notes on R-FW-1/2: built in a sandbox that could not reach `downloads.arduino.cc`; libraries came
from their GitHub release tags and the Arduino prototype generator (ctags) was stubbed — the sketch
declares every function before use. Re-compile on a normal install with
`arduino-cli compile --profile esp32-core3 firmware/Radar_V6` before flashing.

## PHYSICAL validation — all NOT established

Fill in **Result**, **Date** and **By** as you go; put photos or serial logs in `docs/validation/`.
A failed test is still useful — write down what happened.

| ID | Test | Pass criterion | Status | Result | Date | By |
|---|---|---|---|---|---|---|
| T-PRN-1 | Print the fit coupon; try the CYD pegs, sensor-can holes and servo-screw pilots | chosen sizes recorded; `PEG_D`, `CAN_HOLE_D`, `PILOT_D` updated if needed | NOT RUN | | | |
| T-PRN-2 | Print P1 (shell, roof-down) | no supports, chamfers and grooves clean | NOT RUN | | | |
| T-PRN-3 | Print P2 (bezel, base, head) | no supports; pegs not snapped | NOT RUN | | | |
| T-FIT-1 | CYD pressed onto the bezel pegs | firm; screen centred in the window (else set `CYD_VIEW_DX`) | NOT RUN | | | |
| T-FIT-2 | Bezel slides into the shell grooves; base presses in; USB plug reaches the board | nothing forced; base stays in when lifted | NOT RUN | | | |
| T-FIT-3 | Servo screwed under the roof with its own screws; horn pressed into the head foot | head firm on the spline, no wobble | NOT RUN | | | |
| T-FIT-4 | Sensor cans pressed into the head | cans hold; PCB not bent | NOT RUN | | | |
| T-PWR-1 | P1 VIN voltage with USB in: idle, and while the servo moves | ≈ 4.5–5.2 V; record the dip | NOT RUN | | | |
| T-PWR-2 | One-hour run from a ≥ 1 A charger | no resets, flicker or brown-outs (else add the capacitor and re-test) | NOT RUN | | | |
| T-PWR-3 | Run from a laptop USB port | record whether it works; note resets | NOT RUN | | | |
| T-PWR-4 | Current draw with a USB meter: idle and sweeping | record mA | NOT RUN | | | |
| T-FW-1 | Flash; splash, then grid and sweep | as described in ASSEMBLY | NOT RUN | | | |
| T-FW-2 | Panel detection and colours (`# board … panel …` line) | correct picture; else record the `PANEL` / `INVERT_OVERRIDE` / `SWAP_RED_BLUE` that work | NOT RUN | | | |
| T-FW-3 | `CENTER_ONLY` head fit; `REVERSE_SERVO` direction | head faces straight out at 90°; screen matches head | NOT RUN | | | |
| T-FW-4 | Measured timing from the serial "# measured" line | record mean step and one-way sweep (estimate ≈ 115 ms, ≈ 4.6 s) | NOT RUN | | | |
| T-FW-5 | Distance at 30 / 100 / 150 cm on the 90° line (flat target) | record reading vs tape measure | NOT RUN | | | |
| T-FW-6 | Touch: − / + change the range; tap the fan to pause | each tap acts once; no false taps | NOT RUN | | | |
| T-FW-7 | RGB LED turns red under 30 cm | as described | NOT RUN | | | |
| T-CAL-1 | `CALIBRATE_SERVO` against the roof ticks without hitting the end stops | record `SERVO_US_AT_0/180`; no buzzing at ends | NOT RUN | | | |
| T-SWP-1 | Powered sweep with the sensor cable fitted | no rubbing, no cable tug at 30° or 150° | NOT RUN | | | |
| T-THM-1 | Temperatures after 30 min running (board regulator, servo) | nothing uncomfortable to touch | NOT RUN | | | |
| T-LNK-1 | Live console over the scanner's own USB cable at 115 200 baud | readings appear, sweep matches the head; note whether opening the port resets the board | NOT RUN | | | |
| T-LNK-2 | Record a session in the console and replay it | replay matches the live view | NOT RUN | | | |
| T-APP-1 | Windows installer + portable build open and connect | app opens; port picker lists the board | NOT RUN | | | |
| T-APP-2 | macOS build opens (after Gatekeeper approval) and connects | as above | NOT RUN | | | |
| T-FLS-1 | Browser flasher (Flash page, Chrome/Edge) installs the release firmware on a CYD | splash screen appears | NOT RUN | | | |
| T-REL-1 | First tagged release carries the source ZIP, manufacturing kit, firmware, desktop apps, SHA256SUMS and attestations | `sha256sum -c` and `gh attestation verify` pass | NOT RUN | | | |

## Untested assumptions (every VERIFY value in the CAD)

| Variable | Assumed | Source of the assumption | Measured |
|---|---|---|---|
| `CYD_L` × `CYD_H`, `CYD_HOLE_DX/DY` | 86.6 × 50 mm, holes ±39 × ±21 mm | community drawings of the ESP32-2432S028R | |
| `CYD_GLASS_TOP`, `CYD_BACK_DEPTH` | 5.1 mm, 4.8 mm | community STEP model | |
| `CYD_VIEW_DX` | −2.5 mm | community STEP model (active area off-centre) | |
| `CYD_USB_LY/LZ` | −9.3, −1.5 mm | photos; the CYD2USB board's USB-C sits elsewhere — the 15 × 10 mm opening is generous | |
| `SERVO_*` | 22.2 × 11.8 body, 32.2 mm flange, 27.5 mm hole pitch | typical TowerPro SG90 drawings | |
| `HORN_*` | 34 × 6.2 × 1.5 mm single arm, 7.2 mm collar | estimate of a stock horn | |
| `SR04_*` | 45 × 20 mm PCB, Ø16 mm cans, 26 mm pitch | common HC-SR04 / RCWL-1601 footprint | |
| `PEG_D`, `CAN_HOLE_D`, `PILOT_D`, `HORN_SLOT_CLR` | 2.9, 16.2, 1.8, 0.15 mm | print allowances — set from the coupon | |

## Electrical assumptions not yet checked on hardware

* P1 **VIN** carries USB 5 V and can supply an SG90's start-up current (community pinouts say VIN is
  the USB 5 V rail; current capability through the board's protection parts is not measured here).
* The RCWL-1601 / HC-SR04P bought works reliably at 3.3 V (datasheets say 3–5.5 V).
* GPIO 27 and 22 on CN1 and GPIO 35 on P3 are free on your board revision (true for the documented
  ESP32-2432S028R; some clones differ).
* 1000–2000 µs covers 30°–150° of real travel on your servo — probably not exactly; calibrate.

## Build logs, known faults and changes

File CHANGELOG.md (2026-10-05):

# Changelog

## 6.0.0 — 2026-10-04 (Radar V6 "Mini": nicer, fewer parts, cheaper)

New hardware design. Nothing has been physically validated yet.

- **Electronics: 3 modules, 7 wires.** The ESP32 DevKit + 1.8" LCD are replaced by one
  ESP32-2432S028R "Cheap Yellow Display" (ESP32 + 2.8" 320 × 240 touch screen + RGB LED + USB).
  The HC-SR04 + resistor divider is replaced by a 3.3 V RCWL-1601 / HC-SR04P. Wiring goes through the
  board's JST connectors — no breadboard, no soldering to the board.
- **Power: one USB cable.** The 18650 cell, holder, charger/boost module, USB-C breakout, fuse,
  switch and 1000 µF capacitor are gone (and with them the open charger-restart issue).
- **Enclosure: four printed parts, no loose screws.** Ivory console with the screen tilted back 20°,
  a slide-in bezel the CYD presses onto, a press-fit base, and a mint "two-eye" sensor head on a neck.
  Printed without supports; only the two screws that come with the servo.
- **Firmware V6:** 320 × 240 UI with a glowing beam, touch −/+ range (50–400 cm) and pause,
  automatic ILI9341 / ST7789 panel detection, near-object LED, band-buffered drawing, same serial
  format. Live console now works over the scanner's own USB cable.
- Photo-style Cycles renders, an illustrated 7-wire picture, a new parts-kit graphic; BOM, wiring,
  assembly, requirements (33), validation log and build packet rewritten for V6.
- Purchased line items drop from 20 to 5 (+1 optional); estimated parts cost about US$18–30
  (rough single-unit estimate, not a quote).

## 5.2.0 — 2026-10-02 (manufacturing package)

Hardware baseline unchanged (Radar V5.1). Nothing has been physically validated yet.

- `docs/REQUIREMENTS.md`: 36 numbered requirements with verification method and evidence, status
  generated from `VALIDATION.md` (`scripts/gen_traceability.py`) plus a status graphic.
- `manufacturing/`: spreadsheet-ready `bom.csv`, `printed_parts.csv`, pin-by-pin `wiring_pins.csv`,
  point-to-point `wire_list.csv` (W01–W28), and a printable `build_packet.pdf` traveller with tick
  boxes for parts, wires, gates and physical tests — all generated from the docs.
- Visual parts-kit overview (`hardware/diagrams/bom_overview.svg`).
- Browser firmware flasher (Flash page, ESP Web Tools) fed by a firmware image compiled in the Pages
  workflow; firmware images attached to releases.
- Release now also attaches a **manufacturing kit** ZIP (3D files, CSVs, build packet, diagrams, firmware).
- README rewritten to be short and visual.

## 5.1.0 — 2026-10-02 (repository baseline)

First open-source packaging of the Radar V5.1 baseline. Nothing in this release has been physically
validated; see `docs/VALIDATION.md`.

Repository
- CadQuery model of record with every dimension as a named variable and VERIFY marks; one script
  regenerates STL (print orientation), STEP (assembled position + assembly), an A1 mini
  multi-plate 3MF, core-spec plate fallbacks and build-stage plates.
- Recorded geometry checks (79): valid solids, nominal sizes, watertight meshes, plate fit,
  22 interference pairs, ±75° sweep clearance, designed clearances.
- Firmware compiles with zero warnings on Arduino-ESP32 3.3.12 and 2.0.17; versions pinned in
  `sketch.yaml` profiles.
- Wiring, BOM, assembly, printing, equations, validation, security, publishing and glossary docs;
  generated wiring SVGs, callouts, renders and a simulated sweep GIF; GitHub Pages site.
- Tests tie the firmware pins to the wiring net list and encode the wiring safety rules.
- Supply chain: pinned Actions (by commit), least-privilege workflows, Dependabot, CodeQL,
  CycloneDX SBOM, release ZIP with SHA256SUMS and signed build provenance.

Web app and desktop app
- Live console: listen-only Web Serial link, replay of saved logs, labelled demo, session recording
  to CSV; one shared parser (`site/assets/radar-core.js`) tested against the firmware's exact formats.
- Installable web app (manifest + service worker, offline after first visit).
- Desktop app (Electron 44.5.1): locked-down window, serial-port picker, offline KaTeX; Linux AppImage
  + tar.gz, Windows installer + portable, macOS dmg (arm64 + x64) built by the release workflow.
- Optional two-wire telemetry tap (TX0 + GND to a 3.3 V adapter) so the live link never breaks the
  "no ESP32 USB while the harness is connected" rule.

Improvements over the brief
- 45° self-supporting deck under the roof and gussets for the roof screws, so the body prints
  without supports.
- Keyed (one-way) mast/socket with an M2×20 cross-bolt and captive-nut pocket.
- Engraved 30°–150° angle ticks on the turret keeper plus a pointer groove on the hub, used by the
  new `CALIBRATE_SERVO` mode to calibrate travel without hitting the servo stops.
- Hard pulse-width clamp (900–2100 µs) in the firmware, independent of the calibration values.
- Full-frame off-screen buffer for a flicker-free display; measured step and sweep times printed
  over serial each pass; CSV output for the serial plotter.
- LCD SPI clock set to 15 MHz, inside the ST7735S 66 ns write-cycle spec (library default is 32 MHz).
- Range labels moved inside the fan after the display simulator showed them clipped at the edge.
- ESP32 end supports, zip-tie anchors for the cell holder, a USB-C breakout cradle, a sensor-cable
  slot and a rear knock-out reserved for the DFR1026 KEY fall-back.
- Open power issue researched: field reports indicate the DFR1026 may switch off at light load and
  need its KEY; two documented fall-backs (rear KEY button, or PowerBoost 1000C with EN switching).

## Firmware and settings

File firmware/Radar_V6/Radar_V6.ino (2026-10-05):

/*
  Radar_V6.ino — Ultrasonic Radar Scanner, firmware V6 ("Mini")
  -------------------------------------------------------------------------
  EDUCATIONAL ultrasonic (sonar) instrument with a radar-STYLE display.
  NOT radio-frequency radar and NOT a safety or obstacle-avoidance system.
  The angle shown is the COMMANDED servo position, not a measured one.

  Hardware (3 modules, 7 wires, one USB cable):
    * ESP32-2432S028R "Cheap Yellow Display" (CYD): ESP32 + 2.8" 320x240 touch LCD
    * RCWL-1601 / HC-SR04P ultrasonic sensor, powered from 3.3 V (no level shifting)
    * SG90-size positional micro servo, powered from the CYD's P1 VIN (USB 5 V)
  Wiring: docs/WIRING.md is the source of truth; tests/test_sync.py checks the
  PIN_ constants below against it.

  Board   : "ESP32 Dev Module". Libraries: Adafruit GFX, Adafruit ILI9341,
            Adafruit ST7735 and ST7789, Adafruit BusIO, XPT2046_Touchscreen.
            Exact versions are pinned in sketch.yaml. Compiles on Arduino-ESP32
            3.x and 2.x. Compiling is not bench testing — see docs/VALIDATION.md.

  Touch   : tap  −  (bottom left) / + (bottom right) to change the range,
            tap the radar to pause / resume.
  Serial  : 115200 baud, one "angle_deg,distance_cm" line per reading
            (-1 = no echo). The web app's live console reads this over the same
            USB cable that powers the scanner.
*/

#include <Arduino.h>
#include <SPI.h>
#include <Adafruit_GFX.h>
#include <Adafruit_ILI9341.h>
#include <Adafruit_ST7789.h>
#include <XPT2046_Touchscreen.h>
#include <math.h>
#if __has_include("esp_arduino_version.h")
#include "esp_arduino_version.h"
#endif

// =====================================================================
// 1. USER SETTINGS
// =====================================================================
static constexpr bool CENTER_ONLY = false;      // true: hold 90° for fitting the head, then set back to false
static constexpr bool REVERSE_SERVO = false;    // flip if the screen sweeps opposite to the real head
static constexpr bool CALIBRATE_SERVO = false;  // steps 30 -> 90 -> 150 with 4 s holds to compare with the roof ticks

static constexpr int SWEEP_MIN_DEG = 30;        // commanded, not measured
static constexpr int SWEEP_MAX_DEG = 150;
static constexpr int SWEEP_STEP_DEG = 3;
static constexpr uint32_t SETTLE_MS = 70;
static constexpr float MAX_RANGE_CM = 200.0f;   // start-up display range (touch +/- to change)
static constexpr float MIN_RANGE_CM = 2.0f;
static constexpr float AIR_TEMP_C = 20.0f;
static constexpr uint32_t DETECTION_TTL_MS = 10000;
static constexpr float NEAR_CM = 30.0f;         // RGB LED turns red below this

static constexpr uint32_t SERVO_US_AT_0 = 1000;
static constexpr uint32_t SERVO_US_AT_180 = 2000;
static constexpr uint32_t SERVO_US_GUARD_MIN = 900;
static constexpr uint32_t SERVO_US_GUARD_MAX = 2100;

// Display: CYD boards ship with an ILI9341 panel (one USB port) or an ST7789
// panel ("CYD2USB", micro-USB + USB-C). PANEL_AUTO reads the panel ID first.
enum PanelType { PANEL_AUTO, PANEL_ILI9341, PANEL_ST7789 };
static constexpr PanelType PANEL = PANEL_AUTO;
static constexpr int INVERT_OVERRIDE = -1;      // -1 = panel default, 0 = off, 1 = on
static constexpr bool SWAP_RED_BLUE = false;    // set true if reds look blue (some CYD2USB boards)
static constexpr uint32_t TFT_SPI_HZ = 40000000; // common CYD practice; lower to 27 MHz if the picture glitches

// =====================================================================
// 2. PINS (must match docs/WIRING.md — checked by tests/test_sync.py)
// =====================================================================
static constexpr int PIN_TRIG = 27;   // CN1
static constexpr int PIN_ECHO = 35;   // P3, input-only pin; sensor runs at 3.3 V so no divider is needed
static constexpr int PIN_SERVO = 22;  // CN1 (also on P3 - leave that one unconnected)
// on-board, fixed by the CYD layout
static constexpr int PIN_TFT_SCK = 14;
static constexpr int PIN_TFT_MISO = 12;
static constexpr int PIN_TFT_MOSI = 13;
static constexpr int PIN_TFT_CS = 15;
static constexpr int PIN_TFT_DC = 2;
static constexpr int PIN_TFT_BL = 21;
static constexpr int PIN_TOUCH_CLK = 25;
static constexpr int PIN_TOUCH_MISO = 39;
static constexpr int PIN_TOUCH_MOSI = 32;
static constexpr int PIN_TOUCH_CS = 33;
static constexpr int PIN_TOUCH_IRQ = 36;
static constexpr int PIN_LED_R = 4;    // RGB LED, active low
static constexpr int PIN_LED_G = 16;
static constexpr int PIN_LED_B = 17;

// =====================================================================
// 3. FIXED CONSTANTS
// =====================================================================
static constexpr uint32_t SERVO_FREQ_HZ = 50;
static constexpr uint8_t SERVO_RES_BITS = 16;
static constexpr uint8_t SERVO_LEDC_CHANNEL = 0;
static constexpr uint32_t SERVO_PERIOD_US = 1000000UL / SERVO_FREQ_HZ;

static constexpr int SCREEN_W = 320;
static constexpr int SCREEN_H = 240;
static constexpr int BAND_H = 60;                 // render in 4 bands of 320x60 (38 KB each)
static constexpr int FAN_CX = 160;
static constexpr int FAN_CY = 236;
static constexpr int FAN_R = 176;
static constexpr int BIN_COUNT = (SWEEP_MAX_DEG - SWEEP_MIN_DEG) / SWEEP_STEP_DEG + 1;
static constexpr int TRAIL_STEPS = 6;
static const float RANGES_CM[] = {50.0f, 100.0f, 200.0f, 300.0f, 400.0f};
static constexpr int RANGE_COUNT = sizeof(RANGES_CM) / sizeof(RANGES_CM[0]);

// =====================================================================
// 4. STATE
// =====================================================================
SPIClass hspi(HSPI);
SPIClass touchSpi(VSPI);
XPT2046_Touchscreen touch(PIN_TOUCH_CS, PIN_TOUCH_IRQ);
Adafruit_SPITFT *tft = nullptr;
const char *panelName = "?";
GFXcanvas16 band(SCREEN_W, BAND_H);

struct Detection { float cm; uint32_t stampMs; bool valid; };
static Detection detections[BIN_COUNT];
static int sweepDeg = 90;
static int sweepDir = +1;
static int trail[TRAIL_STEPS];
static float rangeCm = MAX_RANGE_CM;
static bool paused = false;
static uint32_t lastPulseUs = 0;
static uint32_t stepStartMs = 0, stepSumMs = 0;
static uint16_t stepCount = 0;
static float nearestThisPass = NAN;
static uint32_t lastTouchMs = 0;

// =====================================================================
// 5. COLOURS
// =====================================================================
static uint16_t rgb(uint8_t r, uint8_t g, uint8_t b) {
  if (SWAP_RED_BLUE) { uint8_t t = r; r = b; b = t; }
  return (uint16_t)(((r & 0xF8) << 8) | ((g & 0xFC) << 3) | (b >> 3));
}
static uint16_t C_BG, C_GRID, C_GRID_TXT, C_SWEEP, C_TEXT, C_DIM, C_WARN, C_BTN;
static void initColours() {
  C_BG = rgb(2, 10, 6);
  C_GRID = rgb(0, 80, 36);
  C_GRID_TXT = rgb(40, 160, 90);
  C_SWEEP = rgb(120, 255, 160);
  C_TEXT = rgb(200, 255, 215);
  C_DIM = rgb(90, 150, 115);
  C_WARN = rgb(255, 190, 60);
  C_BTN = rgb(20, 60, 36);
}
static uint16_t glow(float k) {  // 0..1 -> dark..bright green
  k = constrain(k, 0.0f, 1.0f);
  return rgb((uint8_t)(20 + 150 * k), (uint8_t)(60 + 195 * k), (uint8_t)(30 + 120 * k));
}

// =====================================================================
// 6. SERVO (native LEDC, core 3.x and 2.x)
// =====================================================================
static uint32_t pulseToDuty(uint32_t us) {
  const uint32_t maxDuty = (1UL << SERVO_RES_BITS) - 1;
  return (uint32_t)(((uint64_t)us * maxDuty) / SERVO_PERIOD_US);
}
static void servoBegin() {
#if defined(ESP_ARDUINO_VERSION_MAJOR) && (ESP_ARDUINO_VERSION_MAJOR >= 3)
  ledcAttach(PIN_SERVO, SERVO_FREQ_HZ, SERVO_RES_BITS);
#else
  ledcSetup(SERVO_LEDC_CHANNEL, SERVO_FREQ_HZ, SERVO_RES_BITS);
  ledcAttachPin(PIN_SERVO, SERVO_LEDC_CHANNEL);
#endif
}
static void servoWriteUs(uint32_t us) {
  us = constrain(us, SERVO_US_GUARD_MIN, SERVO_US_GUARD_MAX);
  lastPulseUs = us;
#if defined(ESP_ARDUINO_VERSION_MAJOR) && (ESP_ARDUINO_VERSION_MAJOR >= 3)
  ledcWrite(PIN_SERVO, pulseToDuty(us));
#else
  ledcWrite(SERVO_LEDC_CHANNEL, pulseToDuty(us));
#endif
}
static uint32_t angleToUs(int deg) {
  deg = constrain(deg, 0, 180);
  if (REVERSE_SERVO) deg = 180 - deg;
  return SERVO_US_AT_0 + (uint32_t)((int32_t)(SERVO_US_AT_180 - SERVO_US_AT_0) * deg / 180);
}
static void servoWriteDeg(int deg) { servoWriteUs(angleToUs(deg)); }

// =====================================================================
// 7. ULTRASONIC
// =====================================================================
static float speedOfSoundCmPerUs() { return (331.3f + 0.606f * AIR_TEMP_C) / 10000.0f; }
static uint32_t echoTimeoutUs() {
  return (uint32_t)(2.0f * (rangeCm * 1.1f) / speedOfSoundCmPerUs()) + 1000;
}
static float readDistanceCm() {
  digitalWrite(PIN_TRIG, LOW);
  delayMicroseconds(4);
  digitalWrite(PIN_TRIG, HIGH);
  delayMicroseconds(10);
  digitalWrite(PIN_TRIG, LOW);
  const uint32_t t = pulseIn(PIN_ECHO, HIGH, echoTimeoutUs());
  if (t == 0) return NAN;
  const float cm = (float)t * speedOfSoundCmPerUs() / 2.0f;  // d = v*t/2
  if (cm < MIN_RANGE_CM || cm > rangeCm) return NAN;
  return cm;
}

// =====================================================================
// 8. DISPLAY (mirrored by scripts/sim_display.py for the README GIF)
// =====================================================================
static bool initDisplay() {
  hspi.begin(PIN_TFT_SCK, PIN_TFT_MISO, PIN_TFT_MOSI, PIN_TFT_CS);
  PanelType p = PANEL;
  if (p != PANEL_ST7789) {
    Adafruit_ILI9341 *ili = new Adafruit_ILI9341(&hspi, PIN_TFT_DC, PIN_TFT_CS, -1);
    ili->begin(TFT_SPI_HZ);
    if (p == PANEL_AUTO) {
      const uint8_t id1 = ili->readcommand8(0xD3, 2), id2 = ili->readcommand8(0xD3, 3);
      Serial.printf("# panel id 0xD3: %02X %02X\n", id1, id2);
      p = (id1 == 0x93 && id2 == 0x41) ? PANEL_ILI9341 : PANEL_ST7789;
    }
    if (p == PANEL_ILI9341) { tft = ili; panelName = "ILI9341"; }
    else delete ili;
  }
  if (p == PANEL_ST7789) {
    Adafruit_ST7789 *st = new Adafruit_ST7789(&hspi, PIN_TFT_CS, PIN_TFT_DC, -1);
    st->init(240, 320);
    st->setSPISpeed(TFT_SPI_HZ);
    st->invertDisplay(false);  // CYD2USB panels need inversion off
    tft = st;
    panelName = "ST7789";
  }
  tft->setRotation(1);  // 320 x 240 landscape
  if (INVERT_OVERRIDE >= 0) tft->invertDisplay(INVERT_OVERRIDE == 1);
  pinMode(PIN_TFT_BL, OUTPUT);
  digitalWrite(PIN_TFT_BL, HIGH);
  return band.getBuffer() != nullptr;
}

// drawing helpers: every coordinate is shifted by -y0 so one scene can be painted band by band
static int Y0 = 0;
static inline void P(float deg, float r, int &x, int &y) {
  const float a = deg * (float)DEG_TO_RAD;
  x = FAN_CX + (int)lroundf(r * cosf(a));
  y = FAN_CY - (int)lroundf(r * sinf(a)) - Y0;
}

static void drawButton(int x, int y, const char *label) {
  band.fillRoundRect(x, y - Y0, 56, 36, 8, C_BTN);
  band.drawRoundRect(x, y - Y0, 56, 36, 8, C_GRID);
  band.setTextSize(3);
  band.setTextColor(C_TEXT);
  band.setCursor(x + 19, y + 7 - Y0);
  band.print(label);
}

static void drawScene(int deg, float cm, uint32_t now) {
  band.fillScreen(C_BG);
  // range rings + labels
  for (int q = 1; q <= 4; q++) {
    const float r = FAN_R * q / 4.0f;
    int px, py;
    P(SWEEP_MIN_DEG, r, px, py);
    for (int d = SWEEP_MIN_DEG + 2; d <= SWEEP_MAX_DEG; d += 2) {
      int x, y;
      P(d, r, x, y);
      band.drawLine(px, py, x, y, C_GRID);
      px = x; py = y;
    }
    band.setTextSize(1);
    band.setTextColor(C_GRID_TXT);
    band.setCursor(FAN_CX + 4, FAN_CY - (int)r + 3 - Y0);
    band.print((int)(rangeCm * q / 4));
  }
  for (int d = SWEEP_MIN_DEG; d <= SWEEP_MAX_DEG; d += 30) {
    int x, y;
    P(d, FAN_R, x, y);
    band.drawLine(FAN_CX, FAN_CY - Y0, x, y, C_GRID);
  }
  // fading sweep wedge (trail), newest brightest
  int ox, oy;
  P(deg, FAN_R, ox, oy);
  for (int t = 0; t < TRAIL_STEPS; t++) {
    if (trail[t] < 0) break;
    int x1, y1, x2, y2;
    P(t == 0 ? deg : trail[t - 1], FAN_R, x1, y1);
    P(trail[t], FAN_R, x2, y2);
    band.fillTriangle(FAN_CX, FAN_CY - Y0, x1, y1, x2, y2, glow(0.22f * (TRAIL_STEPS - t) / TRAIL_STEPS));
  }
  // detections: soft halo + bright core, fading with age
  for (int i = 0; i < BIN_COUNT; i++) {
    Detection &d = detections[i];
    if (!d.valid) continue;
    const uint32_t age = now - d.stampMs;
    if (age > DETECTION_TTL_MS) continue;
    const float k = 1.0f - (float)age / DETECTION_TTL_MS;
    int x, y;
    P(SWEEP_MIN_DEG + i * SWEEP_STEP_DEG, FAN_R * d.cm / rangeCm, x, y);
    band.fillCircle(x, y, 5, glow(0.25f * k));
    band.fillCircle(x, y, 3, glow(0.35f + 0.65f * k));
  }
  band.drawLine(FAN_CX, FAN_CY - Y0, ox, oy, C_SWEEP);
  band.fillCircle(FAN_CX, FAN_CY - Y0, 4, C_SWEEP);
  // header
  band.setTextSize(1);
  band.setTextColor(C_DIM);
  band.setCursor(8, 6 - Y0);   band.print("ANGLE (commanded)");
  band.setCursor(128, 6 - Y0); band.print("DISTANCE");
  band.setCursor(236, 6 - Y0); band.print("RANGE");
  band.setTextColor(paused ? C_WARN : C_DIM);
  band.setCursor(282, 6 - Y0); band.print(paused ? "PAUSE" : "LIVE");
  char buf[12];
  band.setTextSize(3);
  band.setTextColor(C_TEXT);
  snprintf(buf, sizeof(buf), "%3d", deg);
  band.setCursor(8, 20 - Y0);  band.print(buf);
  band.setTextSize(2); band.setCursor(64, 26 - Y0); band.print("o");
  band.setTextSize(3);
  band.setCursor(128, 20 - Y0);
  if (isnan(cm)) band.print("---");
  else { snprintf(buf, sizeof(buf), "%3d", (int)lroundf(cm)); band.print(buf); band.setTextSize(2); band.setCursor(184, 26 - Y0); band.print("cm"); }
  band.setTextSize(2);
  band.setTextColor(C_TEXT);
  snprintf(buf, sizeof(buf), "%d", (int)rangeCm);
  band.setCursor(236, 24 - Y0); band.print(buf);
  band.setTextSize(1); band.print(" cm");
  // touch buttons in the corners the fan does not use
  drawButton(6, 198, "-");
  drawButton(258, 198, "+");
}

static void renderFrame(int deg, float cm) {
  const uint32_t now = millis();
  for (int y0 = 0; y0 < SCREEN_H; y0 += BAND_H) {
    Y0 = y0;
    drawScene(deg, cm, now);
    tft->drawRGBBitmap(0, y0, band.getBuffer(), SCREEN_W, BAND_H);
  }
  Y0 = 0;
}

static void splash() {
  tft->fillScreen(C_BG);
  tft->setTextColor(C_TEXT);
  tft->setTextSize(4);
  tft->setCursor(48, 40);
  tft->print("EDU SONAR");
  tft->setTextSize(2);
  tft->setCursor(48, 96);
  tft->print("Ultrasonic radar-style");
  tft->setCursor(48, 118);
  tft->print("scanner - firmware V6");
  tft->setTextColor(C_WARN);
  tft->setCursor(48, 160);
  tft->print("NOT a safety device.");
  tft->setCursor(48, 182);
  tft->print("Angle = commanded.");
}

// =====================================================================
// 9. LED, TOUCH, SERIAL
// =====================================================================
static void led(bool r, bool g, bool b) {  // active low
  digitalWrite(PIN_LED_R, r ? LOW : HIGH);
  digitalWrite(PIN_LED_G, g ? LOW : HIGH);
  digitalWrite(PIN_LED_B, b ? LOW : HIGH);
}
static void printConfig() {
  Serial.printf("# sweep %d..%d deg, step %d, settle %lu ms, range %.0f cm, echo timeout %lu us\n",
                SWEEP_MIN_DEG, SWEEP_MAX_DEG, SWEEP_STEP_DEG, (unsigned long)SETTLE_MS, rangeCm,
                (unsigned long)echoTimeoutUs());
}
static int rangeIndex() {
  for (int i = 0; i < RANGE_COUNT; i++) if (RANGES_CM[i] >= rangeCm - 0.5f) return i;
  return RANGE_COUNT - 1;
}
static void handleTouch() {
  if (!touch.touched() || millis() - lastTouchMs < 300) return;
  lastTouchMs = millis();
  const TS_Point p = touch.getPoint();
  // coarse mapping is enough for three zones (typical CYD raw range 200..3800)
  const int x = map(p.x, 200, 3800, 0, SCREEN_W);
  const int y = map(p.y, 240, 3800, 0, SCREEN_H);
  if (y > 180 && x < 80) {
    rangeCm = RANGES_CM[max(0, rangeIndex() - 1)];
  } else if (y > 180 && x > 240) {
    rangeCm = RANGES_CM[min(RANGE_COUNT - 1, rangeIndex() + 1)];
  } else {
    paused = !paused;
    Serial.println(paused ? F("# paused") : F("# resumed"));
    return;
  }
  for (int i = 0; i < BIN_COUNT; i++) detections[i].valid = false;
  printConfig();
}

// =====================================================================
// 10. SETUP / LOOP
// =====================================================================
static void pushTrail(int deg) {
  for (int t = TRAIL_STEPS - 1; t > 0; t--) trail[t] = trail[t - 1];
  trail[0] = deg;
}

void setup() {
  Serial.begin(115200);
  pinMode(PIN_TRIG, OUTPUT);
  digitalWrite(PIN_TRIG, LOW);
  pinMode(PIN_ECHO, INPUT);
  pinMode(PIN_LED_R, OUTPUT); pinMode(PIN_LED_G, OUTPUT); pinMode(PIN_LED_B, OUTPUT);
  led(false, false, true);

  servoBegin();
  servoWriteDeg(90);  // centre at boot

  initColours();
  const bool bufferOk = initDisplay();
  splash();
  touchSpi.begin(PIN_TOUCH_CLK, PIN_TOUCH_MISO, PIN_TOUCH_MOSI, PIN_TOUCH_CS);
  touch.begin(touchSpi);
  touch.setRotation(1);

  for (int i = 0; i < BIN_COUNT; i++) detections[i] = {NAN, 0, false};
  for (int t = 0; t < TRAIL_STEPS; t++) trail[t] = -1;

  Serial.println(F("# Radar V6 - educational ultrasonic sonar, radar-style display"));
  Serial.printf("# board ESP32-2432S028 (CYD), panel %s, band buffer %s\n", panelName, bufferOk ? "ok" : "FAILED");
  printConfig();
  Serial.println(F("angle_deg,distance_cm   (-1 = no valid echo)"));
  delay(1500);

  if (!CENTER_ONLY && !CALIBRATE_SERVO) {
    for (int d = 90; d >= SWEEP_MIN_DEG; d -= SWEEP_STEP_DEG) { servoWriteDeg(d); delay(25); }
    sweepDeg = SWEEP_MIN_DEG;
    sweepDir = +1;
  }
  led(false, true, false);
  stepStartMs = millis();
}

static void loopCenterOnly() {
  servoWriteDeg(90);
  renderFrame(90, readDistanceCm());
  Serial.printf("# CENTER_ONLY: holding 90 deg (%lu us). Fit the head, then set CENTER_ONLY=false.\n",
                (unsigned long)lastPulseUs);
  delay(1000);
}

static void loopCalibrate() {
  static const int targets[] = {30, 90, 150, 90};
  static uint8_t idx = 0;
  const int deg = targets[idx];
  servoWriteDeg(deg);
  const uint32_t until = millis() + 4000;
  while ((int32_t)(millis() - until) < 0) { renderFrame(deg, readDistanceCm()); delay(200); }
  Serial.printf("# CAL commanded %3d deg -> %lu us. Compare the head with the roof tick.\n", deg,
                (unsigned long)lastPulseUs);
  idx = (idx + 1) % (sizeof(targets) / sizeof(targets[0]));
}

void loop() {
  handleTouch();
  if (CENTER_ONLY) return loopCenterOnly();
  if (CALIBRATE_SERVO) return loopCalibrate();
  if (paused) {
    led(false, false, true);
    renderFrame(sweepDeg, NAN);
    delay(100);
    stepStartMs = millis();
    return;
  }

  servoWriteDeg(sweepDeg);
  delay(SETTLE_MS);
  const float cm = readDistanceCm();
  const int bin = (sweepDeg - SWEEP_MIN_DEG) / SWEEP_STEP_DEG;
  if (bin >= 0 && bin < BIN_COUNT) {
    detections[bin].valid = !isnan(cm);
    detections[bin].cm = cm;
    detections[bin].stampMs = millis();
  }
  if (!isnan(cm) && (isnan(nearestThisPass) || cm < nearestThisPass)) nearestThisPass = cm;
  renderFrame(sweepDeg, cm);
  Serial.printf("%d,%.1f\n", sweepDeg, isnan(cm) ? -1.0f : cm);
  pushTrail(sweepDeg);

  int next = sweepDeg + sweepDir * SWEEP_STEP_DEG;
  if (next > SWEEP_MAX_DEG || next < SWEEP_MIN_DEG) {
    sweepDir = -sweepDir;
    next = sweepDeg + sweepDir * SWEEP_STEP_DEG;
    const bool near = !isnan(nearestThisPass) && nearestThisPass < NEAR_CM;
    led(near, !near, false);  // proximity colour for the pass that just ended
    nearestThisPass = NAN;
    if (stepCount) {
      Serial.printf("# measured: %u steps, mean step %.1f ms, one-way sweep %.2f s\n", stepCount,
                    (float)stepSumMs / stepCount, stepSumMs / 1000.0f);
    }
    stepSumMs = 0;
    stepCount = 0;
  }
  const uint32_t now = millis();
  stepSumMs += now - stepStartMs;
  stepCount++;
  stepStartMs = now;
  sweepDeg = next;
}

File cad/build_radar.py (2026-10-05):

"""
Radar V6 "Mini" — CadQuery model of record for the Ultrasonic Radar Scanner.

Three electronic modules, four printed parts, no screws beyond the ones that
come with the servo:

  01_shell    console body: tilted screen opening, roof with the turret hole,
              engraved angle scale, USB hole. Printed roof-down, no supports.
  02_bezel    screen frame that slides into the shell; the Cheap Yellow Display
              (CYD) presses onto four printed pegs on its back. Printed face-down.
  03_base     bottom plate: press-fits into the shell and locks the bezel.
  04_head     "two-eye" sensor head with neck and horn foot. Printed face-down.
  05_fit_coupon  print FIRST: peg, transducer-hole, servo-hole and pilot tests.

Coordinates (assembled, mm): origin at the centre of the footprint on the table.
  +X right (seen from the screen side), +Y towards the scan side (the sensor
  looks along +Y at 90 degrees), +Z up. The screen faces -Y (towards you).

Every dimension is a named variable. VERIFY marks values that depend on the
modules you bought — measure them and print 05_fit_coupon first.
Nothing here has been printed or fitted yet — see docs/VALIDATION.md.
"""
from __future__ import annotations

import math
from dataclasses import dataclass

import cadquery as cq

# ============================================================================
# 0. PRINT ALLOWANCES
# ============================================================================
FIT = 0.20                 # general sliding clearance per side
PEG_D = 2.90               # CYD mounting-hole pegs (holes are 3.2 mm). VERIFY with coupon
PILOT_D = 1.80             # pilot for the servo's own self-tapping mounting screws. VERIFY with coupon
CAN_HOLE_D = 16.20         # transducer press-fit holes. VERIFY with coupon (cans are ~16 mm)

# ============================================================================
# 1. PURCHASED MODULES (all VERIFY)
# ============================================================================
# ESP32-2432S028R "Cheap Yellow Display" (landscape, display facing +lz)
CYD_L, CYD_H = 86.6, 50.0          # PCB (community drawing: 86 x 50, holes 78 x 42 apart)
CYD_PCB_T = 1.6
CYD_HOLE_DX, CYD_HOLE_DY = 39.0, 21.0
CYD_HOLE_D = 3.2
CYD_DISP_W, CYD_DISP_H = 69.0, 50.0  # display module on the front
CYD_GLASS_TOP = 5.1                # front of the glass above the PCB back (lz)
CYD_STANDOFF = 3.6                 # bezel back -> PCB front at the holes (glass top 3.5 above PCB front + 0.1)
CYD_VIEW_W, CYD_VIEW_H = 58.0, 43.6  # 2.8" active area 57.6 x 43.2 + margin
CYD_VIEW_DX = -2.5                 # active-area centre vs PCB centre (community STEP model). VERIFY
CYD_BACK_DEPTH = 4.8               # tallest part behind the PCB (connectors)
CYD_USB_LY, CYD_USB_LZ = -9.3, -1.5  # micro-USB at the +X edge (local), VERIFY
USB_HOLE_W, USB_HOLE_H = 15.0, 10.0  # side-wall opening; fits micro-USB and the USB-C of CYD2USB boards

# SG90-size positional servo (TowerPro envelope)
SERVO_BODY_L, SERVO_BODY_W = 22.2, 11.8
SERVO_FLANGE_L, SERVO_FLANGE_T = 32.2, 2.5
SERVO_FLANGE_BELOW = 15.9          # body bottom -> flange underside
SERVO_CASE_ABOVE = 6.8             # flange underside -> top of rectangular case
SERVO_BOSS_ABOVE = 10.8            # flange underside -> top of round gear boss
SERVO_SPLINE_ABOVE = 15.1          # flange underside -> top of output spline
SERVO_BOSS_D = 11.8
SERVO_HOLE_PITCH = 27.5
SERVO_SHAFT_OFFSET = 5.5           # shaft -> body centre along the long axis
HORN_LEN, HORN_ARM_W, HORN_ARM_T = 34.0, 6.2, 1.5
HORN_COLLAR_D = 7.2
HORN_ARM_BELOW_SPLINE = 0.5        # arms sit this far below the spline top

# RCWL-1601 / HC-SR04P ultrasonic sensor (HC-SR04 footprint)
SR04_PCB_L, SR04_PCB_W, SR04_PCB_T = 45.0, 20.0, 1.6
SR04_CAN_D, SR04_CAN_H, SR04_CAN_PITCH = 16.0, 12.0, 26.0
SR04_HEADER_W = 11.0

# ============================================================================
# 2. 01_SHELL
# ============================================================================
W, D, H = 104.0, 96.0, 62.0        # width, depth, height
TILT_DEG = 20.0                    # screen leans back from vertical
WALL, TOP = 2.4, 2.4
R_REAR = 12.0                      # rounded rear corners (plan)
R_FRONT = 5.0                      # front corners
CH_ROOF = 3.5                      # 45-degree roof chamfer (prints on the bed without overhang)
CH_BOTTOM = 0.8
Y_TURRET = 16.0                    # turret axis
TURRET_HOLE_D = 13.0               # gear boss + spline pass through, nothing else shows
SERVO_BOSS_H = 6.0                 # bosses under the roof; servo hangs from them
SERVO_BOSS_DIA = 4.6                # must clear the servo case (hole pitch/2 - case/2 = 2.65 mm)
WIRE_SLOT = (12.0, 5.5)            # sensor cable pass-through
WIRE_SLOT_R = 27.0                 # distance from the turret axis towards the screen
TICK_R0, TICK_R1 = 30.5, 36.0      # engraved angle scale on the roof
ENGRAVE = 0.6

# ============================================================================
# 3. 02_BEZEL
# ============================================================================
RECESS = 3.0                       # bezel sits this far behind the shell front edge (a deep frame)
BEZEL_T = 2.4
GROOVE_D, GROOVE_CLR = 1.0, 0.25   # side-wall grooves the bezel slides into
BEZEL_BOTTOM_Z = 2.6               # bezel bottom edge rests on the base plate
BEZEL_TOP_GAP = 0.2
WINDOW_CHAMFER = 1.2
CYD_V_OFFSET = 4.0                 # board centre above the bezel's mid-height (leaves a chin for the label)

# ============================================================================
# 4. 03_BASE
# ============================================================================
BASE_T = 2.4
BASE_CLR = 0.15
BASE_RIM_H, BASE_RIM_T = 5.0, 1.6
BASE_RIM_SIDE_FROM_Y = -8.0        # side rims start here (clear of the screen area)

# ============================================================================
# 5. 04_HEAD
# ============================================================================
HEAD_W, HEAD_H = 56.0, 30.0
HEAD_R = 9.0
HEAD_DEPTH = 15.0                  # open-backed visor
HEAD_FACE_T = 2.4
HEAD_AXIS_BEHIND_FACE = 10.0       # rotation axis sits this far behind the face (towards you)
NECK = 10.0                        # square neck
NECK_GAP = 5.0                     # foot top -> head bottom
FOOT_L, FOOT_D, FOOT_T = 36.0, 20.0, 4.5
HORN_SLOT_CLR = 0.15               # tight: the horn is pressed into the foot. VERIFY

# ============================================================================
# 6. 05_FIT_COUPON
# ============================================================================
COUPON_W, COUPON_D, COUPON_T = 92.0, 42.0, 3.0
COUPON_PEGS = (2.8, 2.9, 3.0)
COUPON_CANS = (16.0, 16.2, 16.4)
COUPON_PILOTS = (1.6, 1.8, 2.0)
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

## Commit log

2026-10-02 Ultrasonic Radar Scanner v5.2.0: open-hardware package (CAD, BOM, wiring, build packet, firmware, web + desktop apps)
    [01_body.step, 01_body.stl, 02_front_panel.step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]
2026-10-05 Ultrasonic Radar Scanner v6.0.0: Radar V6 Mini - 3 modules, 7 wires, 4 printed parts (CAD, BOM, wiring, build packet, firmware, web + desktop apps)
    [01_body.step, 01_body.stl, 01_shell.step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]

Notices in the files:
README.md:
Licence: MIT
